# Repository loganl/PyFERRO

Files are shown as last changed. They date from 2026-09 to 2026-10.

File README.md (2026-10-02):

# PyFERRO — PHY445 phase-transition lab

Instrument control and data acquisition for a physics teaching lab: a lock-in amplifier
measures a sample's dielectric response while a PID controller ramps its temperature
through a phase transition. PyFERRO reads both instruments, plots live, and writes
self-describing data files. It replaces `FERRO v.2.vi`, a LabVIEW 2009 routine.

This repository holds the program and the lab manual for the experiment it serves.

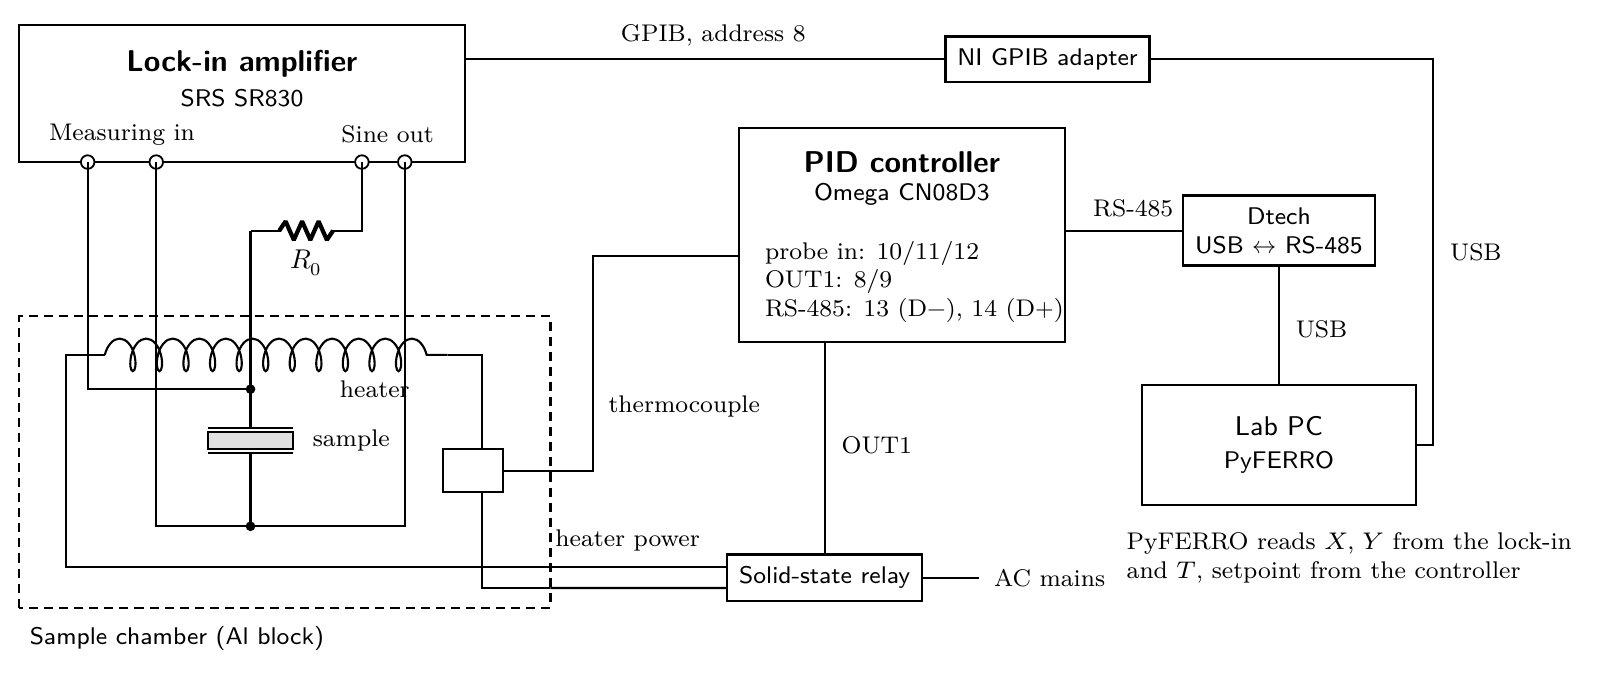
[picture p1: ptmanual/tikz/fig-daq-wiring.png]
Instrument wiring


## Try it without hardware

Needs [pixi](https://pixi.sh) only — it fetches Python and every dependency itself.

```bash
git clone https://github.com/loganl/PyFERRO.git
cd PyFERRO/pyferro
pixi run simulate          # the full GUI, driven by simulated instruments
pixi run -e test test      # the test suite: no hardware needed, GUI tests run offscreen
```

Simulation sits *below* the drivers, so the same parsing, scaling and file-writing code
runs as in the lab. Against real instruments it is `pixi run start`.

## Layout

| Path | What it is |
|---|---|
| `pyferro/ferro/` | the program: `gui/`, `acquisition.py` (the measurement loop), `instruments/` (drivers), `transports.py` (GPIB/serial), `config.py`, `datafile.py`, `analysis.py`, `sessionlog.py` |
| `pyferro/tools/` | `update.py` (the `git pull` before `pixi run start`) and `gpib_check.py` (`pixi run gpib`, a GPIB link diagnostic) |
| `pyferro/tests/` | drivers, wire-level protocol tests over a pty, GUI tests, version consistency |
| `pyferro/docs/` | `drivers-and-daq.md` and the instrument manuals |
| `ptmanual/` | LaTeX source of the lab manual, its figures and standalone TikZ sources |

**[`pyferro/README.md`](pyferro/README.md) is the complete documentation** — install,
wiring, taking data, file format, instrument protocols, code layout, tests and
releases. [`pyferro/docs/drivers-and-daq.md`](pyferro/docs/drivers-and-daq.md)
walks through the transports, drivers and measurement loop, and
[`pyferro/CHANGELOG.md`](pyferro/CHANGELOG.md) records each version.

## The hardware it talks to

| Instrument | Link | Protocol |
|---|---|---|
| SRS SR830 lock-in | GPIB (NI adapter), address 8 | IEEE 488.2 text commands, X/Y/R/θ in volts; its settings can also be set from the program |
| Omega CND3 PID controller | RS-485 via an FTDI USB adapter | Modbus ASCII/RTU, read-only |
| HP 34401A multimeter (optional) | GPIB, address 24 | `READ?`, Pt100 → °C (IEC 60751) |

The Instruments tab can also select the lab's previous lock-in, an **EG&G/PAR 5302**
(GPIB 12 on this rig), and a **Keithley 199** multimeter (GPIB 6).

The controller owns the heater; PyFERRO never writes to it. Instrument failures are
recorded as `nan` with a flag bit and the connection is reopened automatically, so a
dropped cable does not end a measurement.

The manuals for all five instruments are in `pyferro/docs/manuals/`, and the protocol
tests check the drivers against the example frames printed in them.

## How it ships

The lab PC runs a git clone of this repository (`C:\PyFERRO`) with pixi.
`pixi run start` does a `git pull --ff-only` first, so the lab always runs the latest
code on `main`; being offline just starts the copy already there. There is no
installer or bundle to build.

## Versioning

`MAJOR.MINOR.PATCH`, tagged `v<version>`. The number is written in exactly one place,
`__version__` in `pyferro/ferro/__init__.py`; the package metadata, the window title and
every data-file header derive from it, and a test fails if a second copy
appears or a tag disagrees. A file recorded in the lab names the version that produced
it, so it can always be traced back to the code.

## The lab manual

```bash
cd ptmanual && make        # builds the TikZ figures, then main.pdf
cd ptmanual && latexmk     # the same without make, for machines that lack it
cd ptmanual && make tagged # main-tagged.pdf, the tagged PDF/UA-2 edition for screen readers
```

It is built with **LuaLaTeX** from **TeX Live 2024 or newer** — the tagged-PDF
metadata and `luamml` are too new for older releases, and Debian's and Ubuntu's
packages lag behind. `ptmanual/.latexmkrc` and a `% !TEX program = lualatex` line in
every source file select the engine, so no flag is needed. The PDFs are committed,
so reading the manual needs no TeX at all. What to install, editor set-up and the
Overleaf route are in [`ptmanual/README.md`](ptmanual/README.md).

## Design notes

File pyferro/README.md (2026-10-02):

# PyFERRO — phase-transition data acquisition

Records **sample temperature** and the **lock-in X/Y signal** while an Omega CND3 PID
controller heats and cools the chamber. Replaces the LabVIEW routine `FERRO v.2.vi`.

| Instrument | Connection | Default |
|---|---|---|
| SRS SR830 lock-in | NI GPIB adapter | `GPIB0::8::INSTR` |
| Omega CND3 PID controller (holds the control thermocouple) | Dtech USB → RS-485 (FTDI) | Modbus ASCII, address 1, 9600 7E1 |
| HP 34401A multimeter (optional) | NI GPIB adapter | `GPIB0::24::INSTR`, Pt100 in 4-wire Ω |

Other models can be chosen on the Instruments tab: the lab's previous lock-in, an EG&G/PAR
5302 (GPIB 12 on this rig), and a Keithley 199 multimeter (GPIB 6). Choosing a lock-in
model moves the address to that model's, unless it was typed in by hand.

PyFERRO **reads** the controller and never changes its setpoints or heater power, so
the controller's *COMMUNICATION WRITE* setting stays **OFF**. The lock-in is the one
instrument it can set, from the Lock-in tab, and only when asked (§3).

This file is the complete documentation. [`CHANGELOG.md`](CHANGELOG.md) records what
changed per version; [`docs/drivers-and-daq.md`](docs/drivers-and-daq.md) explains the
code that talks to the instruments; `docs/` also holds the instrument manuals.

## 1. Install on the lab PC

Windows 10/11 64-bit. The lab PC runs a git clone at `C:\PyFERRO`.

1. Install [Git for Windows](https://git-scm.com/download/win) and
   [pixi](https://pixi.sh) (in PowerShell:
   `powershell -ExecutionPolicy ByPass -c "irm -useb https://pixi.sh/install.ps1 | iex"`).
   Neither needs admin rights.
2. Clone: `git clone https://github.com/loganl/PyFERRO.git C:\PyFERRO`.
3. Install the drivers once:
   * **NI-VISA** + **NI-488.2** for the GPIB adapter. A 64-bit VISA is required
     (`C:\Windows\System32\visa64.dll`); 32-bit-only installs from the LabVIEW 2009 era
     cannot be used from 64-bit Python.
   * **FTDI VCP driver** for the Dtech adapter, only if it does not appear as a `COM`
     port in Device Manager.
4. Start it from a terminal in `C:\PyFERRO\pyferro`:
   * `pixi run start` pulls the latest code (§8), then runs against the instruments;
   * `pixi run simulate` runs without hardware;
   * `pixi run gpib` diagnoses the lock-in's GPIB link (§5).

   The first start downloads Python and every dependency into `.pixi\` (allow
   ~1.5 GB of disk); later starts reuse it. After that, a start needs no internet:
   offline, the update step says so and the program starts as it is.

## 2. Hardware and wiring

wiring diagram

This is the lab manual's own figure: full size in
`../ptmanual/tikz/fig-daq-wiring.pdf`, source in `fig-daq-wiring.tex` beside it.

**RS-485** (two-wire half-duplex; the adapter's `RXD+`, `RXD-`, `GND` stay empty):

| Dtech terminal | CND3 terminal |
|---|---|
| `T/R+` | **14** (`D+`) |
| `T/R-` | **13** (`D−`) |

If the controller does not answer, swap the two wires first. Terminal numbers are those
of the 1/8 DIN size (CN08D3 = Delta DT340); other sizes number them differently.

**Controller settings** (Initial Setting mode): communication enabled, protocol ASCII,
address 1, 9600 baud, 7 data bits, even parity, 1 stop bit, communication write OFF.
Other settings work — use *Auto-detect settings*. The CND3 cannot use 7N1, 8O2 or 8E2.

**Identifying the controller:** during the first 3 s after power-on the top display's
4th character is `C` when RS-485 is fitted, and the bottom display's first two letters
are the OUT1/OUT2 types (`R` relay, `V` voltage pulse, `C` current, `L` linear voltage,
`S` SSR, `N` none). The lab unit is 43.8 × 90.9 mm behind the bezel (1/8 DIN, cutout
44.5 × 91.5 mm), 100–240 V AC.

**Lock-in:** the SR830, GPIB address 8. The sensitivity and expand settings are read
from the instrument with every reading, so X and Y are always scaled correctly. The rest
of the set-up follows the lab manual's SR830 table (for the 5302, the set-up from the
manual's former 5302 table):
*Test lock-in* compares the instrument with it, and the Lock-in tab can set it (§3).

**Multimeter (optional):** the HP 34401A must be switched to **4-wire Ω** on its front
panel — PyFERRO does not change its function, and on 2026-09-29 it was found set to DC
volts. The Keithley 199 is set to ohms by PyFERRO on every connection and picks 2- or
4-wire by whether the SENSE leads are connected, but its **FRONT/REAR** input switch is
mechanical: it must select the terminals the Pt100 is wired to.

**Safety:** the chamber is hot above 100 °C and the lab manual forbids exceeding 160 °C.
PyFERRO warns above that but is not a safety device; the controller and relay are.

## 3. Taking data

1. **Instruments tab:** check the lock-in **Model** (SRS SR830 on this rig), pick the
   Dtech COM port (FTDI ports listed first), press **Test lock-in** and
   **Test controller**. A green ✔ shows the sensitivity, time constant and reference
   frequency, and PV/SV, output level, control mode and firmware. A table underneath
   compares every lock-in setting with the lab manual's table for that model and says
   which key changes any that differ; starting a recording repeats the check and logs
   any difference as a warning.
2. **Lock-in tab:** shows the chosen model's settings. *Read from lock-in* fills them in;
   change them there and press *Apply to lock-in* (it lists the commands and asks
   first), or press *Lab-manual values* to fill in the lab manual's table, then Apply.
   Only what differs is sent, and the settings are read back afterwards. This works
   during a run too: the change is sent between samples and written into the data file.
   The phase tuning stays on the front panel, as does turning an SR830 offset or expand
   on (the tab can turn them off), and on the 5302 its AC/DC and FLOAT/GND keys.
3. **Run tab:** enter a sample/run name (becomes the file name), operator, drive details,
   notes, and the save folder.
4. **▶ Start monitoring** (F5) shows live data without saving. **● Record** (Ctrl+R)
   opens a file, starting monitoring if needed; pressing it again closes that file, and
   the next recording opens a new one. **■ Stop** disconnects.
5. Set the **reading interval** to at least ~5× the lock-in time constant.
   *Save only if ΔT ≥* reproduces the old LabVIEW behaviour; leave it off to record
   every reading.
6. **Temperature from** (Run tab) selects what goes in column 1 of the file: the
   *CND3 controller* probe (normal) or the *Multimeter Pt100*. Both are recorded
   whenever available — `PV_C` from the controller, `T_dmm_C` from the multimeter.
   To use the multimeter, tick **Also read the multimeter** on the Instruments tab and
   check its model, its GPIB address (`GPIB0::24::INSTR` for the 34401A,
   `GPIB0::6::INSTR` for the Keithley 199 on this rig) and whether the reading is ohms
   (a Pt100, converted here) or already °C (34401A only).

The tiles above the plots show the sample temperature, setpoint, ramp direction and
rate, X, Y and R/θ; the plots show temperature against time and X and Y against
temperature, heating and cooling in different colours.

Status lights: green OK, red not answering (hover for the reason), grey unused. A failed
reading never stops a run — the value becomes `nan`, a flag is set, and the instrument is
reopened after three consecutive failures. The first three temperatures after the
controller or multimeter connects are discarded (`nan`, flag 16) so a start-up glitch
cannot squash the plot. The temperature tile turns red above the
chamber limit (default 160 °C).

Settings persist in `%USERPROFILE%\.ferro\settings.json`; delete it to reset, or set
`FERRO_CONFIG_DIR` for a per-group file.

## 4. Data files

`<name>_YYYYMMDD_HHMMSS.txt`, never overwritten, flushed after every row.

```
# created: 2026-09-29T15:02:11
# software: pyferro 1.1.0
# sample: BTO_1V_37kHz
# temperature_source: CND3 controller PV
# lockin_model: SR830
# lockin_sensitivity: 1 V
# lockin_time_constant: 300 ms
# lockin_setup_check: matches the lab manual's SR830 table
# controller_sv_c: 150.0
# column 1: T_C - sample temperature used for plots (degC)
# T_C	X_V	Y_V	time_s	R_V	theta_deg	SV_C	PV_C	T_dmm_C	sens_V	direction	segment	flags
2.71944e+01	1.00420e-04	-2.32000e-03	0.00000e+00	...
```

| # | Column | Meaning |
|---|---|---|
| 1–3 | `T_C`, `X_V`, `Y_V` | as in the LabVIEW files: temperature (°C), lock-in X and Y (V rms) |
| 4 | `time_s` | seconds since the run started |
| 5–6 | `R_V`, `theta_deg` | √(X²+Y²) and atan2(Y, X) |
| 7–8 | `SV_C`, `PV_C` | controller setpoint and temperature |
| 9 | `T_dmm_C` | multimeter Pt100 temperature (`nan` when unused) |
| 10 | `sens_V` | lock-in full-scale sensitivity at that moment |
| 11–12 | `direction`, `segment` | +1 heating, −1 cooling, 0 not yet known; segment increments at each turn-around. The column switches 1–2 min after a turn; the `# Ramp turned … at T °C, t = … s` line in the file gives where it really was |
| 13 | `flags` | 1 lock-in overload, 2 lock-in error, 4 controller error, 8 multimeter error, 16 temperature discarded just after connecting (added together) |

Missing values are `nan`. Load with `numpy.loadtxt(path)`, or:

```python
names = "T_C X_V Y_V time_s R_V theta_deg SV_C PV_C T_dmm_C sens_V direction segment flags".split()
df = pd.read_csv(path, sep=r"\s+", comment="#", names=names)
heating = df[df.direction == 1]
```

*Old LabVIEW file format* writes only T, X, Y with no header (readable by `plot.vi`);
the metadata then goes to a `.json` file of the same name.

**Events inside the file.** Anything that changes what the numbers mean is written into
the data file as a `#` comment line at the moment it happens — a sensitivity or time
constant change, and any change of reference, oscillator level or frequency, filters,
reserve, input, coupling, grounding, displays or phase (checked every minute, and at once after a
change from the Lock-in tab, which is itself recorded), an overload starting or clearing, the controller switching to STOP, a
changed reading interval or temperature source, edited notes. `numpy.loadtxt` and pandas
skip these lines, so nothing breaks; the header also names the port each instrument used
(`# connection_lockin:`, `# connection_pid:`).

**Session log.** Everything the log panel shows is also written to
`~/.ferro/logs/pyferro_<start>.log`, from the moment the program starts — so the
messages that explain a run (an instrument that never answered, an auto-detect that
found nothing) survive even though they happened before recording began. Each data file
names it in its header (`# session_log:`) and gets a copy beside it as `<name>.log` when
the recording closes, so the data and its explanation travel together. The twenty newest
logs are kept; a log that cannot be written is skipped silently and never interrupts a
measurement.

## 5. Troubleshooting

| Symptom | Cause and fix |
|---|---|
| `update: …` line at start | `pixi run start` says what its `git pull` did. Offline, a local edit in the way, or a folder that is not a clone never stops the start; if it says the dependencies changed, close and start again. |
| `pixi` or `git` is not recognised | Not installed, or the terminal was opened before installing; install it (§1) and open a new terminal. |
| Qt/DLL errors at start-up | The clone is on a network drive; clone to a local disk. |
| `Could not open GPIB0::12::INSTR` | NI-VISA/NI-488.2 missing, adapter unplugged, or wrong address — check NI MAX. |
| Lock-in connects only sometimes | Run `pixi run gpib`: it opens a fresh connection twenty times, as a program start does, and reports the success rate. Use it before and after reseating a connector or swapping a cable, rather than trusting a single Test. |
| NI MAX says the 5302 "did not respond to a \*IDN? query" | Normal: the 5302 predates `*IDN?` (it answers `ID`). The scan did find it. |
| *Find* lists no VISA instruments | 32-bit-only NI-VISA; install a current one with `visa64.dll`. |
| GPIB reads all time out, but the bus enumerates | **Another instrument on the chain is powered off.** GPIB's handshake needs every connected device powered; an unpowered one holds NRFD/NDAC low, which also makes a scan "find" a device that never answers. Switch the multimeter on — even when PyFERRO is not using it — or take it out of the cable chain. |
| Readings arrive far slower than the interval | An instrument that is not answering costs its whole timeout every sample. The log says which one, every 30 s. |
| `expected ID 5302, instrument answered …` | Another instrument at that GPIB address. |
| X values ×10 off | Check the EXPAND (`EX`) indicator; it multiplies X only. PyFERRO accounts for it, the LabVIEW VI did not. |
| X/Y tile red "OVERLOAD" | Signal beyond 120 % of full scale — use a less sensitive range. |
| "Lock-in settings differ from the lab manual" | A setting is not the lab manual's value; the Instruments tab's table says which key changes it, or use the Lock-in tab. A warning only — recording goes ahead. |
| Readings jump between rows | Interval shorter than ~5× the time constant. |
| `No valid reply from CND3` | Wrong COM port, wires swapped (14 = D+, 13 = D−), communication disabled, or different settings — run *Auto-detect settings*. |
| `temperature sensor not connected` | The controller reports a probe fault (`8003H`); check terminals 10/11/12. |
| `controller initialising` | Normal for a few seconds after power-on (`8002H`). |
| `controller sent …H, a status code, not a temperature` | A value below −999.9 °C, which no input can read. The first readings after connecting are discarded for this reason (flag 16); if it recurs mid-run, check the probe wiring. |
| `multimeter reads … expected ~100-200 ohm` | The 34401A is not in 4-wire Ω (set it on the front panel), or the Pt100 is not connected. |
| Keithley 199 reads `OOHM+9.999999E+9` / "overflow" | Open circuit: nothing across the inputs in use. Check the Pt100 leads and that the FRONT/REAR switch selects the terminals they are on. |
| Temperature in °F | The controller is set to Fahrenheit; PyFERRO records what it reports. |
| COM port disappears | FTDI/driver issue or unplugged adapter; press *Refresh* — the loop reconnects by itself. |
| Nothing is saved | The Record button must be red; check the log panel. |
| "Cannot save here" / write error mid-run | Folder read-only or the USB drive vanished; rows already written are intact. |
| Fewer rows than expected | *Save only if ΔT ≥* is set. |
| Plots slow after hours | Press **Clear plots**; the file is unaffected. |

## 6. Instrument protocols

Manuals in `docs/manuals/`. `tests/test_protocols.py` checks
the code against the example frames printed there.

**EG&G 5302** (manual chapters 8–9): `ID` → `5302`; `XY` → X and Y with **±10000 = full
scale** (±12000 max); `SEN`/`SEN n` sensitivity index 0–21 (100 nV … 1 V, 1-2-5);
`XTC`/`XTC n` time-constant index 0–18; `EX` → 1 when Expand X is on (x channel ×10, y unaffected);
`FRQ` → reference frequency in mHz. The front-panel set-up is read with `IE` (reference
INT/TTL/EXT), `OA` and `OF` (oscillator level and frequency, each as a count and a
range), `DR` (dynamic reserve), `FLT` (filter), `PREAMP` (signal input) and `P`
(reference phase), and each command with a number sets that value — how the Lock-in tab
applies the lab manual's table. AC/DC coupling and FLOAT/GND have no command.

`V = counts / 10000 × full_scale`, with X (only) divided by 10 when expand is on. `SEN` and `EX` are
read before every `XY`. `XY` is the compound command `X;Y`, so the two numbers arrive
either on one line (separated by the `DD` delimiter) or as two terminated lines — the
driver reads a second line when only one number arrives. GPIB (address 12) or RS-232;
over RS-232 the instrument echoes characters and ends each exchange with `*` (OK) or
`?` (error/overload/unlock), at 9600 7E1.

**Omega CND3 / Delta DT340:** Modbus ASCII (default) or RTU, function 03H reads up to
8 words, 06H writes one. PV and SV are read in one request.

| Register | Content |
|---|---|
| `1000H` | present value (PV), signed, 0.1° units |
| `1001H` | set value (SV), signed, 0.1° units |
| `1005H` | control method: 0 PID, 1 ON/OFF, 2 manual, 3 fuzzy |
| `1012H`, `1013H` | output 1 and output 2 levels, 0.1 % units |
| `102AH` | LED status: bit 2 = °C, bit 3 = °F |
| `102FH` | firmware version (`0x0100` = V1.00) |
| `103CH` | run/stop: 0 STOP, 1 RUN, 2 END, 3 HOLD |
| `1104H`, `1124H` | setpoint ramp rate (0.1°) and its unit (0 per minute, 1 per second) |
| `110EH` | output 1 upper limit, 0.1 % units |
| `1120H` | setpoint mode: 0 constant, 1 slope, 2 program, 3 remote |

PV and SV are read every sample; the control method and run state every minute; the
rest by *Test controller* and for the data-file header.

PV values `8002H` initialising, `8003H` sensor not connected, `8004H` sensor input error,
`8006H` ADC error, `8007H` memory error are faults, not temperatures. *Auto-detect* tries
ASCII then RTU across the documented baud rates and framings, reading `102FH`.
Limitation: during a ramp `1001H` holds the programmed setpoint; the moving setpoint
(`1036H`, program mode) is not read.

**HP 34401A:** `*IDN?` to identify; `READ?` returns the displayed value. PyFERRO does
not set the function: in 4-wire ohms (set on the front panel) that is the Pt100
resistance, converted with IEC 60751 (`R = R₀(1 + AT + BT²)`, A = 3.9083×10⁻³,
B = −5.775×10⁻⁷). A reading outside 0.5–3 × R₀ (50–300 Ω for a Pt100) raises an error
naming the likely cause. With *Reading* set to °C the value is recorded as it comes.

**SRS SR830** (manual chapter 5), GPIB only, LF terminators both ways, address 8:
`OUTX 1` at connection so answers go to GPIB, `*IDN?` to identify. Each sample reads
`SENS?` (index 0–26, 2 nV … 1 V), `OEXP? 1/2/3` (offset and expand of X, Y and R),
`SNAP? 1,2,3,4` (X, Y, R, θ in volts and degrees, X and Y from one instant), then
`LIAS?`. That status byte latches and is cleared by reading it, so an overload at any
time since the previous sample sets the overload flag. Reading the byte clears it, so
if the read needs a retry the sample is flagged as overloaded too. The manual does not say whether
`SNAP?` includes the output offset and expand; when either is set, at the start or
later, the log says so and the header records them, so check the recorded X/Y against the display.
The set-up is read with `FMOD?` (reference), `FREQ?`, `SLVL?` (sine output level),
`ISRC?`, `ICPL?`, `IGND?` (input, coupling, grounding), `ILIN?` (line notches), `RMOD?`
(reserve), `OFSL?` (filter slope), `DDEF? 1/2` (displays) and `PHAS?`, and each command
with a value sets it — how the Lock-in tab applies the lab manual's table. Several go on
one line separated by `;` (5-1), which is how `OEXP 1,0,0;OEXP 2,0,0;OEXP 3,0,0` turns
every offset and expand off. The sine output's resistance is 50 Ω: the lab manual's R₀.

**Keithley 199** (manual section 3.9): no `*IDN?`; `U0X` returns a status word starting
`199`. Connecting sends a device clear, which resets the meter, so the program sets
ohms, autorange, zero off and prefixed readings itself (`F2R0T0B0Z0G0X`). Readings look like
`NOHM+1.100000E+2`: a leading `O` means overload and is reported as an error rather
than as its all-9s value, and anything other than `OHM` means someone changed the
function. The 199 picks 2- or 4-terminal ohms by whether the SENSE leads are
connected. It has no °C function, so only the Pt100 reading is offered.

## 7. Code layout

```
ferro/gui/          main_window.py  window, plots, readouts, log
                    setup_panel.py  instrument settings, Test / Auto-detect
                    lockin_panel.py the Lock-in tab: read and set the lock-in
                    widgets.py      status lights, readouts, background tasks
ferro/acquisition.py   the measurement loop: open, read, log, retry
ferro/instruments/  lockin5302.py, sr830.py, cnd3.py,
                    hp34401a.py, keithley199.py, simulated.py
ferro/transports.py VisaTransport (GPIB), SerialTransport (RS-232 echo + prompt)
ferro/config.py     settings dataclasses, saved as JSON
ferro/datafile.py   the writer
ferro/analysis.py   ramp-direction tracking
ferro/sessionlog.py the session log
tools/update.py     the git pull before pixi run start
tools/gpib_check.py pixi run gpib: step-by-step GPIB diagnosis with a verdict
```

[`docs/drivers-and-daq.md`](docs/drivers-and-daq.md) walks through the transports, the
instrument drivers and the acquisition loop in depth, with the real bytes from this rig.

Each loop pass first handles a Record or Lock-in-tab request; then reads the
controller, the multimeter if enabled, then the lock-in; picks the temperature source;
updates direction and segment; emits the row to the GUI; writes it when recording;
re-reads the slower settings once a minute; and sleeps to the next tick without
catching up. Instrument I/O
happens only on the acquisition thread and reaches the GUI through Qt signals; *Test*
buttons and the stop sequence run as short-lived worker tasks; each transport serialises
its own calls with a lock.

## 8. Tests and simulation

```bash
pixi run start                     # git pull, then run against the real instruments
pixi run start --skip-deps         # the same without updating first
pixi run simulate                  # the GUI with simulated instruments
pixi run gpib [GPIB0::12::INSTR]   # diagnose the 5302's GPIB link (it asks ID, so 5302 only)
pixi run -e test test              # everything (GUI tests run offscreen)
pixi run -e test test -k protocol  # one group
```

`pixi` installs the environment on first use; no other setup is needed on a development
machine (macOS, Linux or Windows).

`pixi run start` first runs `tools/update.py`, which does `git pull --ff-only` so a
git clone (such as the lab PC's `C:\PyFERRO`) always starts on the latest code. It never
stops the program starting: offline ("update: offline", after at most 10 s), a local
edit in the way, or a folder that is not a clone each print one line and start the code
as it is. If the pull changed the
dependencies, it says to close and start again so pixi can install them.

| File | Covers |
|---|---|
| `tests/test_core.py` | scaling, parsing, register decoding, Pt100, every driver against a fake of its manual's protocol, setting both lock-ins and checking them against the lab manual, data files, direction tracking, settings, a simulated run |
| `tests/test_protocols.py` | real serial/Modbus code over a pty against manual-accurate emulators (skipped on Windows) |
| `tests/test_gui.py` | record/stop cycles, run-name guard, one file per recording, plots after Clear, window width, the Test button for every model, other models recorded and kept in the settings, the Lock-in tab for each model, idle and during a run, the address following the model |
| `tests/test_version.py` | one version everywhere, matching the git tag |

`tools/` has no tests: `update.py` and `gpib_check.py` are checked by running them.

Simulated instruments sit **below** the drivers, so the same parsing and scaling code
runs: a shared fake sample ramps 25 → 150 → 25 °C at 30 °C/min with a peak at 122 °C,
and the controller exposes the CND3 registers. Whichever lock-in is chosen on the
Instruments tab starts in the lab manual's set-up for it, apart from a 50 mV
sensitivity, and accepts the Lock-in tab's commands: the SR830 answers its own commands
in volts, the 5302 `ID`/`SEN`/`XTC`/`EX`/`FRQ`/`XY` with counts scaled to the current
range. The Keithley 199 gives prefixed ohms readings. Simulated runs show an orange
banner and `simulation: True` in the file header. Simulation cannot reproduce timing,
bus noise, wiring faults or GPIB itself — check those with the *Test* buttons and
`pixi run gpib`.

## 9. Versioning and releases

One number, in one place:

```python
# ferro/__init__.py
__version__ = "1.1.0"
```

`pyproject.toml` takes it dynamically, the window title and every data-file header show
it, `pixi.toml` has no version field, and the release is tagged `v<version>`.
`tests/test_version.py` fails if a second copy appears or the tag disagrees.

The lab PC runs whatever is on `main`, so a release is a tag marking a tested state,
not something to install. To release, on an up-to-date, clean `main`:

```bash
# 1. edit __version__ in ferro/__init__.py, and add "## 1.1.0 — <date>" to CHANGELOG.md
pixi run -e test test
git commit -am "PyFERRO 1.1.0"
git tag -a v1.1.0 -m "PyFERRO 1.1.0"
git push origin main v1.1.0
```

Patch: fixes and docs. Minor: features, new options, a column added on the right.
Major: data-layout or workflow changes that break existing analysis scripts.

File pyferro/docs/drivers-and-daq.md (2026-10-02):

# Drivers and DAQ

How PyFERRO turns bytes on a GPIB cable and an RS-485 pair into a row in a data file —
from the wires up to the measurement loop, with every example taken from this rig.

1. [The layers](#1-the-layers)
2. [The wires](#2-the-wires-just-enough-to-read-the-code)
3. [Transports](#3-transports)
4. [Drivers](#4-drivers)
5. [DAQ](#5-daq)
6. [One sample, traced](#6-one-sample-traced)
7. [Check yourself](#7-check-yourself)

## 1. The layers

| Layer | Files | Job |
|---|---|---|
| GUI | `gui/main_window.py`, `setup_panel.py`, `lockin_panel.py` | Draws plots and readouts. Never talks to an instrument the loop has open. |
| **DAQ** | `acquisition.py` | When to read, what to do when a read fails, what to save. |
| **Drivers** | `instruments/sr830.py`, `lockin5302.py`, `cnd3.py`, `hp34401a.py` (+ other models, §4) | What the instrument's answers mean. |
| **Transports** | `transports.py`, minimalmodbus | How bytes get there and back. |
| OS / vendor | NI-VISA → NI-488.2; pyserial → FTDI | Hardware access, from outside this repo. |
| Wires | GPIB → SR830 (or 5302); RS-485 → CND3 terminals 13/14 | Electrical signals. |

Each layer talks only to the one directly below it. `Lockin5302` never mentions GPIB;
`Acquisition` never mentions `SEN`. That separation is why simulation works: replace the
bottom of the stack and everything above runs unchanged. This document covers the three
layers in bold.

## 2. The wires, just enough to read the code

### GPIB (IEEE-488)

A parallel bus: eight data lines plus control lines. One **controller** — the NI
GPIB-USB-HS, at address 0 — shares it with up to 30 devices, each with a **primary
address**. The 5302 is PAD 12. Before data moves, the controller *addresses* the bus:
"12, listen" or "12, talk".

Every byte crosses with a three-wire handshake:

- **NRFD**, not ready for data — a listener holds it until it can take a byte
- **DAV**, data valid — the talker asserts it once the byte is on the lines
- **NDAC**, not data accepted — a listener holds it until it has the byte

So the bus runs at the speed of its slowest listener. Two failures seen on this rig
follow directly: an **unpowered instrument** holds these lines down and nothing moves;
and **"no listeners" (ENOL)** means NRFD and NDAC were both released when the controller
started — nobody was there to hold them.

A message ends with the **EOI** line on its last byte, and/or a **terminator byte**: CR
(`0x0D`) or LF (`0x0A`). Two more bus operations appear in the code. A **serial poll**
reads one status byte from a device, answered by its interface chip rather than its
command processor. **Device Clear** resets a device's interface and buffers.

### RS-485

The signal is the voltage *difference* between two wires, D+ and D−, which makes it
resistant to noise. It is half-duplex — one side talks at a time — and multi-drop, so
the protocol carries a device address; the CND3 is Modbus address 1. The Dtech adapter
appears to Windows as an ordinary COM port.

Characters travel as asynchronous serial. At **9600 7E1** each is 1 start + 7 data + 1
parity + 1 stop bit = 10 bits, about **1.04 ms per character**.

### VISA

A vendor-neutral API: open a *resource* by name (`GPIB0::12::INSTR`), then write, read,
set a timeout, set terminators, read the status byte, clear. NI-VISA implements it on
NI-488.2; **pyvisa** wraps it for Python. The `@py` backend, pyvisa-py, is pure Python
and **cannot** drive NI GPIB hardware.

## 3. Transports

Source: [`ferro/transports.py`](../ferro/transports.py)

Every driver needs exactly three calls, and that is the whole contract:

```python
write(cmd)          # send; no reply expected
query(cmd) -> str   # send; return the reply text
close()
```

`VisaTransport` and `SerialTransport` implement it for real hardware, and the simulator
has one fake per instrument model (`SimLockinTransport` for the 5302, `SimSR830Transport`,
`SimDMMTransport`, `SimK199Transport`).

### Terminators, as actual bytes

This is what `ibic` showed on the rig:

| Direction | Bytes | Meaning |
|---|---|---|
| PC → 5302 | `49 44 0D` | "I" "D" CR — write termination CR |
| 5302 → PC | `35 33 30 32 0D` | "5" "3" "0" "2" CR — read termination CR |

pyvisa appends `write_termination` to everything it sends, and stops reading at
`read_termination`. If that byte never comes, the read runs to the timeout and fails
with `VI_ERROR_TMO` — indistinguishable from a dead instrument. `None` means stop only
on EOI.

`probe_terminations` tries each pair in `TERMINATIONS` in order. It is generic: the
caller passes in `open_one(write, read)` and `verify(transport)`, so it knows nothing
about the 5302. It keeps the first pair that verifies, closes every rejected transport,
and tags the winner with `.terminators` so the caller can try that pair first next time.

### `VisaTransport`, method by method

- **`__init__`** tries NI-VISA, then `@py`; opens the resource; sets the timeout (in ms)
  and both terminators; sends **Device Clear**, which also empties replies a previous
  program never collected.
- **`_lock`** exists because two threads can reach one instrument: the acquisition loop
  and a **Test** button's worker. Without it their bytes interleave on the bus and each
  reads the other's reply.
- **`query`** loops `retries + 1` times. After a failure it serial-polls and decodes the
  status byte, drains stale replies, then tries again. When the retries run out it
  raises `TransportError` with the decoded reason attached, and `retries_used` counts
  how often it had to.
- **`_pause`** is the 50 ms gap: the 5302 loses a command that arrives while it is still
  busy with the last one.
- **`reply_delay_s`** is a second 50 ms wait, between sending a query and reading its
  reply (`pyvisa`'s `query(delay=...)`). The instrument must parse the command before it
  can talk; addressed too soon, its reply is late and the *next* query reads it. On the
  rig this was the difference between the Test button failing 10 times in 10 and
  succeeding 15 in 15. The multimeter leaves it at 0.
- **`_recover` / `drain_replies`** handle a subtle trap. A query that *times out* can
  still have its reply arrive afterwards, and then the *next* query reads that late
  reply instead of its own — which is how `5302` once turned up as a sensitivity index.
  Draining with a 200 ms timeout discards anything in flight.
- **`read`** fetches one more line, for when `XY`'s two values arrive separately.

### `SerialTransport` — the same contract over RS-232

Over RS-232 the 5302 echoes each character, sends its reply ending in CR LF, and then
sends a **prompt**: `*` if all is well, `?` on an error. `_exchange` clears the input
buffer, writes, reads 64-byte chunks until the tail ends in a prompt, and strips the
echo. It accepts a prompt in only three positions: as the whole message, after a CR/LF,
or right after the echoed command (a command with no reply).

> The prompt marks the end of every exchange, so serial replies **cannot** get out of
> step. GPIB has no such marker — which is why the VISA side needs draining and range
> checks and the serial side does not.

## 4. Drivers

### Lock-in: `Lockin5302`

Source: [`ferro/instruments/lockin5302.py`](../ferro/instruments/lockin5302.py)

| Command | Returns |
|---|---|
| `ID` | `5302` |
| `SEN` | sensitivity index 0–21: 100 nV to 1 V in a 1-2-5 sequence |
| `EX` | 1 when Expand X is on |
| `XTC` | time-constant index 0–18 |
| `FRQ` | reference frequency in **mHz** |
| `XY` | X and Y as integer **counts** |
| `IE`, `DR`, `FLT`, `PREAMP` | codes for reference mode, dynamic reserve, filter, signal input |
| `OA`, `OF` | oscillator level and frequency as `n1 n2`: a count and its range |
| `P` | reference phase as `quadrant millidegrees` |

The last three rows are read by `setup()`, for the **Test** button, the data-file header,
the Lock-in tab and the once-a-minute poll during a run (§5) — a record of how the front
panel was set, following the 5302 capacitance set-up. Each is read on its own and becomes
`not read` if it fails, so a dropped exchange there cannot fail a Test or a recording.
AC/DC coupling and FLOAT/GND are latching keys with no GPIB command and cannot be read
at all.

**Setting the 5302.** Every command above that reads a value also sets it when given a
number: `SEN 21`, `XTC 8`, `EX 0`, `IE 0`, `OF 2500 7`, `OA 5000 1`, `DR 1`, `FLT 0`,
`PREAMP 1`. `SETTABLE` lists what the driver can set, in the order `apply()` sends it
— the time constant before the reserve, because a FAST time constant forces MIN reserve
(manual §4.3). `commands_for` builds every command, checking each value, before
`apply()` sends the first, so a bad value sends nothing. `oscillator_frequency_command`
and `oscillator_level_command` do the count-and-range encoding: 25 kHz is `OF 2500 7`
(2500 in the 10–100 kHz decade), 0.5 V is `OA 5000 1` (5000 steps of 0.1 mV).

**Checking the set-up.** `CAPACITANCE_SETUP` is the 5302's capacitance set-up as data
— setting, wanted value, and which front-panel key changes it — and
`check_setup(settings)` compares a `settings()` dict with it row by row: ✔, ✘, or "not
read". The Test button shows the result as a table, a recording writes it into the
header (`# lockin_setup_check:`), and the Lock-in tab's *Lab-manual values* fills its
form from the same table. It was the lab manual's 5302 table until the manual moved to
the SR830 and dropped the 5302; the SR830 driver's `CAPACITANCE_SETUP` is the one to keep
in step with `ptmanual/main.tex` now.

The instrument speaks **counts, not volts**. ±10000 counts is full scale; readings run to
±12000 before clipping.

```
V = counts / 10000 × full_scale[SEN]
X only: ÷ 10 again when EX = 1
```

**Expand multiplies the gain of the x channel only** — manual §4, "causes the x channel
output to be multiplied by 10". Y keeps its full scale.

Worked example: `SEN` answers 17 (50 mV full scale) and `XY` answers `5000,-2500`. Then
X = 5000/10000 × 50 mV = **25 mV** and Y = **−12.5 mV**. With Expand on, X becomes
**2.5 mV** and Y stays **−12.5 mV**.

**Why `read()` asks for `SEN` and `EX` every sample:** if a student presses SEN↑
mid-run, the same counts now mean different volts. The LabVIEW routine scaled with a
value stored once at the start, which is how the 2025 data came out pinned at
1.00×10⁻⁷ V. Two short exchanges per sample buy scaling that cannot go stale. If either
fails, the sample is lost rather than guessed.

- **`XY`** may arrive on one line or two. The regex collects every integer; if it found
  only one, the driver reads another line.
- **`parse_ints`** matches `[-+]?\d+`, so it ignores whatever delimiter separates the
  values — the `DD` command can set any character.
- **`checked_index`** treats an index outside 0–21 or 0–18 as "replies out of step", not
  as a range we don't know about. The manual's tables 9-16 and 9-19 match ours.
- **`LockinReading`** carries the result, with derived `r_v` = √(X²+Y²), `theta_deg`,
  `overloaded` (≥ 12000 counts) and `percent_fs`.

### Controller: `CND3` and minimalmodbus

Source: [`ferro/instruments/cnd3.py`](../ferro/instruments/cnd3.py)

**Modbus in brief.** The device is a table of 16-bit **registers**. Function **03**
reads a run of them. A request names the device address, the function, a start register
and a count; the reply gives a byte count, then the values; a checksum closes every
frame. Here is the request PyFERRO sends every sample:

```
:  01  03  1000  0002  EA  CR LF
│  │   │   │     │     └─ LRC checksum
│  │   │   │     └─ read 2 registers: PV and SV
│  │   │   └─ starting at register 1000H (PV)
│  │   └─ function 03, read
│  └─ Modbus address 1
└─ start of frame
```

**LRC:** add the bytes, `01+03+10+00+00+02 = 0x16`, then take the two's complement,
`(−0x16) & 0xFF = 0xEA`.

The reply is `:01 03 04 05DC 0640 D1`: four data bytes, where `05DC` = 1500 →
**150.0 °C** process value and `0640` = 1600 → **160.0 °C** setpoint.

`decode_temperature` checks the fault codes 8002H–8007H first, then reads the word as
signed 16-bit and divides by ten: `FFF6` → 65526 − 65536 = −10 → **−1.0 °C**. Anything
below −999.9 °C is refused as a status code: no input goes that low, and an unlisted
code such as `8000` would otherwise become **−3276.8 °C** — the "−3000 °C" spikes once
seen on the first readings of a run.

**Who does what.** minimalmodbus builds the frame, computes the LRC (or CRC-16 for RTU,
the same content in raw binary), sends it through pyserial, and validates the reply's
checksum, address and function. `CND3` just asks for `read_registers(0x1000, 2)` and
interprets the answer. Its `_read` retries twice, sleeping 50 ms then 100 ms, and it
**never writes** — so it cannot touch the setpoint or the heater. `autodetect` works
through mode × baud × framing, asking for the firmware register until something answers.

Beyond PV and SV, `status()` gathers what **Test controller** shows and the data-file
header records: firmware, output 1 level, control method (1005H), run state (103CH) and
°C/°F, plus `setup()` — output 2, output 1's upper limit, the setpoint mode and its ramp
rate. Like the 5302's `setup()`, each of those is read on its own and becomes `None` if
it fails, because they explain a run rather than measure it.

On the wire, 17 characters out and 19 back is about **37 ms**, plus the controller's own
response time.

### Multimeter: `HP34401A`

Source: [`ferro/instruments/hp34401a.py`](../ferro/instruments/hp34401a.py)

`READ?` returns whatever the meter is measuring: the driver sends no function command,
so the meter must be put in 4-wire ohms on its front panel. The driver solves the
Callendar–Van Dusen quadratic R = R₀(1 + A·T + B·T²) for T: 109.73 Ω → 25.0 °C,
157.33 Ω → 150.0 °C. A sanity window of 0.5–3 × R₀ catches a meter left in the wrong
mode — on the rig it was once found on DC volts.

### Other models: one shape, several drivers

The lab's lock-in is now the SRS SR830, the default; the 5302 above, its predecessor, is
still supported, and the walkthrough uses it because its quirks are the instructive
ones. The multimeter can be a 34401A or a Keithley 199. `open_lockin` and `open_dmm`
look the driver up in `LOCKIN_MODELS` / `DMM_MODELS`, and nothing above them knows which
one they got, because every lock-in driver has the same methods (`check`, `read`,
`settings`, `apply`, `close`) and attributes (`MODEL`, `SENSITIVITY_LABELS`,
`TIME_CONSTANT_LABELS`, `EXPAND_NAME`), and every reading the same fields (`x_v`, `y_v`,
`r_v`, `theta_deg`, `sensitivity`, `full_scale_v`, `percent_fs`, `expand`,
`overloaded`). The multimeters share `check`, `read_raw`, `read_celsius`, `close` and
`MODEL`.

Each lock-in driver also describes its own settings, so the GUI and the loop need no
per-model code: `SETUP_TABLE` (its lab-manual table, checked by the shared
`check_setup`), `SETUP_NAME`, `SETUP_NOTE`, `PANEL` (the Lock-in tab's controls:
key, label, and a kind — a choice, a position in a list, kHz, volts or a check box),
`PANEL_NOTE` (what only the front panel can do), and `commands(changes)`, which builds
and checks every command before anything is sent. The Lock-in tab rebuilds itself from
`PANEL` when the model changes.

What differs is what the manuals say, and each difference shows up somewhere specific:

- **SR830** ([`sr830.py`](../ferro/instruments/sr830.py)) is IEEE 488.2 and does its own
  flow control, so it gets fixed LF terminators and none of the 5302's delays. It answers
  in volts, so there is no scaling. Its overload status byte **latches and clears on
  read**. The driver reads it exactly once per sample, after the data. Two reads (say one
  for overload, one for unlock) would each clear what the other was looking for. For the
  same reason a retried read may have lost the bits, so a sample whose status read
  needed a retry is flagged as overloaded. Every front-panel setting has a command, so
  unlike the 5302 nothing is unreadable: `setup()` reads `FMOD?`, `SLVL?`, `ISRC?`,
  `ICPL?`, `IGND?`, `ILIN?`, `RMOD?`, `OFSL?`, `DDEF?` and `PHAS?`. `SETTABLE` sends the
  reference first (`FREQ` is refused unless it is internal) and the reserve and slope
  before the time constant, which the instrument raises to the shortest they allow.
  Several commands can share a line, separated by `;`: that is how one entry turns
  every offset and expand off.
- **Keithley 199** ([`keithley199.py`](../ferro/instruments/keithley199.py)) has no
  `*IDN?`, like the 5302. The device clear that `VisaTransport` sends on opening resets
  it, so the driver sets its own function, and turns Zero off, every time. Its readings carry a prefix, and
  that prefix is the only place an overload shows: without it, overflow is a
  plausible-looking 9.999999E+9 Ω.

### Simulation

Source: [`ferro/instruments/simulated.py`](../ferro/instruments/simulated.py)

The fakes sit **below** the drivers. `SimLockinTransport` implements the transport
contract and answers `SEN`, `XY` and the rest as a 5302 would — starting in the lab
manual's set-up, and taking new values from `SEN 21`-style commands — so the real
parsing, scaling and setting code runs. `SimSR830Transport` does the same with the
SR830's commands, in volts. `SimModbusInstrument` stands in for `minimalmodbus.Instrument`, so the real
`decode_temperature` runs. One shared `SimulatedSample` keeps all three instruments
agreeing on the temperature. `lockin_transport` and `dmm_transport` pick the fake that
matches the selected model.

## 5. DAQ

Source: [`ferro/acquisition.py`](../ferro/acquisition.py)

### Threads

| Thread | Job | May block? |
|---|---|---|
| GUI (Qt) | draw, respond to clicks | **Never** — the window would freeze |
| Acquisition | all instrument I/O | Yes, for seconds |

They communicate three ways. **Callbacks** (`on_sample`, `on_log`, `on_status`,
`on_recording`), which the GUI wraps in Qt signals so they queue safely across threads.
**Stop**, a `threading.Event`. And **Record on/off**, a request variable under
`_req_lock` that the loop picks up at the top of its next pass — only the acquisition
thread ever opens or closes the data file.

### Opening instruments

`open_lockin` picks the driver for the selected model, then branches: simulated, SR830
(GPIB with LF terminators, nothing to probe), serial, or GPIB. The GPIB path, used by
the 5302, runs the terminator probe with a short timeout and **no
retries**, so a wrong pair fails fast; caches the winning pair per resource; then
restores the full timeout and turns retries on. `open_pid` and `open_dmm` are simpler;
`open_dmm` gives the Keithley 199 its CR LF terminators.

### `InstrumentSlot`: one state machine per instrument

```
 off ──get() opens it──► ok ◄── a read succeeds
  ▲                      │
  │ 3 failures: close,   │ a read fails
  │ reopen after 5 s     ▼
  └────────────────── error
```

`get()` opens the device lazily, and while the 5-second backoff runs it raises "waiting
to reconnect" instead. `failed()` counts failures, and on the third closes the device and
schedules a reopen.

The two thermometer slots, controller and multimeter, also have `discard_after_open`
(`DISCARD_TEMPERATURES_AFTER_OPEN`, 3). Every successful open, at the start of a run or
on a reconnect, resets `to_discard` to it, and that many readings are thrown away before
any is trusted.

### `_read`: the wrapper around every instrument call

- It times the call — the source of the "falling behind" message's numbers.
- On the **first** failure it logs one warning. It is edge-triggered: one message when
  something breaks, not one per sample.
- When a device recovers it logs "answering again after N s".
- On failure it returns `None`, and the caller records NaN plus a flag.
- While a slot still has readings to discard it returns `DISCARDED`: the instrument
  answered (its light stays green), but the caller records NaN with flag 16, not the
  error flag.

### `_run`: the clock

Readings follow an **absolute schedule**, `next_tick = t0 + n × interval`, so sleep errors
never accumulate into drift. With a 0.2 s interval and a 0.15 s reading, the loop sleeps
0.05 s. If a reading takes 2.1 s, `delay` comes out negative, so the loop resets the
schedule to *now* rather than firing a burst of catch-up reads, and warns at most every
30 s.

It waits with `_stop.wait(delay)` rather than `sleep`, so Stop wakes it instantly. The
body sits inside `try/except` so one bad sample can't kill the thread, and `finally`
closes the file and instruments however the loop ends.

### `_sample`: building one row

It reads the controller, then the multimeter if enabled, then the lock-in, into a dict
whose keys are the file's columns. A failure becomes NaN plus a **flag bit**:

| Bit | Value | Meaning |
|---|---|---|
| 0 | 1 | lock-in overload |
| 1 | 2 | lock-in error |
| 2 | 4 | controller error |
| 3 | 8 | multimeter error |
| 4 | 16 | temperature discarded just after connecting |

The bits add, so `flags = 6` means the lock-in and the controller both failed that
sample. `T_C` then comes from whichever temperature source is selected, the ramp
direction updates, and the over-temperature alarm fires once, as the limit is crossed.

### Ramp direction: `DirectionTracker`

Source: [`ferro/analysis.py`](../ferro/analysis.py)

The rig's temperature readings wobble by degrees around the ramp, whether from the
heater cycling or a noisy probe. A local slope follows every swing — the first version of this tracker used one and flipped
between heating and cooling on each. So the tracker does two things instead:

1. **Average** the temperature over the last 120 s. Swings much faster cancel out.
2. **Turn only at a turning point.** While heating it remembers the highest average
   reached, and calls the ramp cooling once the average is **3 °C** below that peak;
   the mirror image while cooling. A wobble smaller than the band never turns it,
   however steep.

| State | Becomes | When |
|---|---|---|
| 0, not yet known | heating / cooling | the average has moved 3 °C from where it started |
| heating | cooling | the average is 3 °C below the highest it reached |
| cooling | heating | the average is 3 °C above the lowest it reached |

A turn is recognised a minute or two after the real extreme. At that moment
`just_turned` is set and `turn_time_s` / `turn_temp_c` give the extreme, so `_sample`
annotates the file (`# Ramp turned to cooling at 150.1 °C, t = 7512 s …`) and the
window recolours the points since then. The rows already written keep the old label.

On synthetic 25 → 150 → 25 °C runs at 1–10 °C/min with ±5 °C swings of period 5–120 s it
turned exactly once every time, within 4 s of the true peak; the old slope tracker
turned hundreds of times once the swings were 30 s or slower. `segment` counts the
turns; `slope_c_per_min`, for the display only, is a least-squares slope of the averaged
temperature over the last 120 s.

### Watching settings

`_watch_lockin` runs every sample and costs nothing, since SEN, EX and overload arrive
with each reading. `_poll_settings` runs every 60 s: the lock-in's full `settings()`
(the reference, oscillator, filters, reserve, input and phase, and on the SR830 also
coupling, grounding, slope and displays — `LOCKIN_WATCHED` lists what is compared) and the controller's mode and run
state, which each need extra exchanges. Any change is **annotated** — logged, and
written into the data file as `# HH:MM:SS …` — so the file explains itself. Each poll
also goes to `on_lockin`, which fills the window's Lock-in tab.

### Changing lock-in settings during a run

The window never talks to an instrument the acquisition thread has open: two threads
on one GPIB device would interleave their bytes. So the Lock-in tab calls
`set_lockin(changes)`, which only stores the request under `_req_lock`, like
`set_recording`. At the top of its next pass the loop's `_handle_lockin_request` sends
it with the driver's `apply()`, annotates what was sent (`Lock-in set from PyFERRO:
filter FLAT (FLT 0)`), and brings the next poll forward, so the read-back — and any
"changed to" line — follows at once. The file therefore shows both what was asked for
and what took effect. `apply()` checks every value before sending the first command,
and sends the time constant before the reserve, since a FAST time constant forces MIN
reserve. When no run is active the tab opens its own connection instead, like Test.

### Recording

Source: [`ferro/datafile.py`](../ferro/datafile.py)

`_handle_record_request` picks up the Record button. `_open_writer` creates a unique path
and writes a header including the instrument settings read at that moment. `_maybe_write`
applies the ΔT gate. `DataWriter.write` writes a tab-separated row and **flushes and
fsyncs every row**, so a power cut loses at most one. `_close_writer` closes the file and
copies the session log beside it.

## 6. One sample, traced

A 0.2 s interval with both instruments healthy:

| t (s) | Layer | What happens | On the wire |
|---|---|---|---|
| 0.000 | DAQ | `_run` tick → `_read("pid")` | |
| | Transport | minimalmodbus → pyserial, ~18 ms out | `:010310000002EA␍␊` |
| | Transport | reply, ~20 ms + controller | `:01030405DC0640D1␍␊` |
| | Driver | `[1500, 1600]` → PV 150.0 °C, SV 160.0 °C | |
| ≈ 0.05 | DAQ | `_read("lockin")` → `Lockin5302.read()` | |
| | Transport | sensitivity, then 50 ms gap | `SEN␍` → `17␍` |
| | Transport | expand, then 50 ms gap | `EX␍` → `0␍` |
| | Transport | data, then 50 ms gap | `XY␍` → `5000,-2500␍` |
| | Driver | X 25 mV, Y −12.5 mV at 50 mV full scale | |
| ≈ 0.22 | DAQ | row built, direction updated, `on_sample` → Qt queue → plots; row written and fsynced | |
| | DAQ | `next_tick` was 0.2 and has passed → no sleep this time | |

> The lock-in's three 50 ms gaps alone take 150 ms. **A 0.2 s interval is just below
> what this rig can sustain** — 0.25 to 0.3 s is the realistic floor.

## 7. Check yourself

<details><summary>The lock-in returns <code>12000,300</code> with SEN = 15, EX = 0. What is X, and which flag is set?</summary>

12000/10000 × 10 mV = **12 mV**. 12000 counts is the overload threshold, so flag value
**1**.
</details>

<details><summary>SEN = 17, EX = 1, and <code>XY</code> answers <code>4000,4000</code>. What are X and Y?</summary>

Full scale is 50 mV. X = 4000/10000 × 50 mV ÷ 10 = **2 mV**. Expand is X only, so
Y = 4000/10000 × 50 mV = **20 mV**.
</details>

<details><summary>Why does <code>SerialTransport</code> never need <code>drain_replies</code>?</summary>

Every serial exchange ends at a prompt, `*` or `?`, so a reply can't spill into the next
exchange.
</details>

<details><summary>The CND3's PV word is <code>FF38</code>. What temperature is that?</summary>

65336 − 65536 = −200 → **−20.0 °C**.
</details>

<details><summary>At a 1 s interval, the RS-485 wires come loose for 20 s. What appears in the log and the file?</summary>

One warning when it breaks. Rows get PV = NaN with flag **4**. On the third failure the
slot closes and retries roughly every 5 s, logging each attempt. When the wires
reconnect: "answering again after ~20 s".
</details>

<details><summary>The loop is sleeping between samples. Why does Stop still respond immediately?</summary>

It waits with `_stop.wait(delay)`, which returns the moment the Stop event is set.
</details>

<details><summary>What goes wrong if the GUI thread calls <code>Lockin5302.read()</code> directly?</summary>

The window freezes for every instrument delay — several seconds on a timeout.
</details>

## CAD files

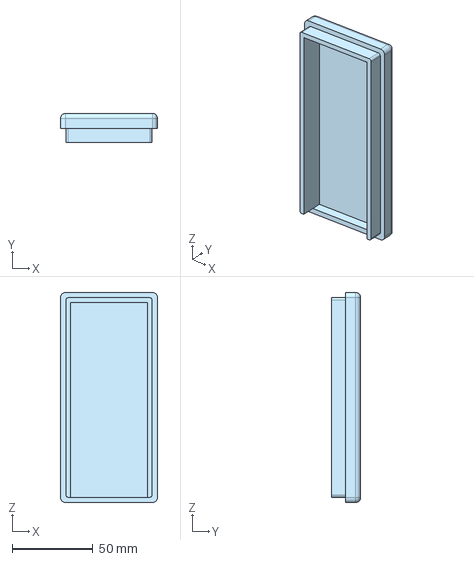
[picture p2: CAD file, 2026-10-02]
cadfiles/lid.step
60.0 x 18.0 x 130.0 mm

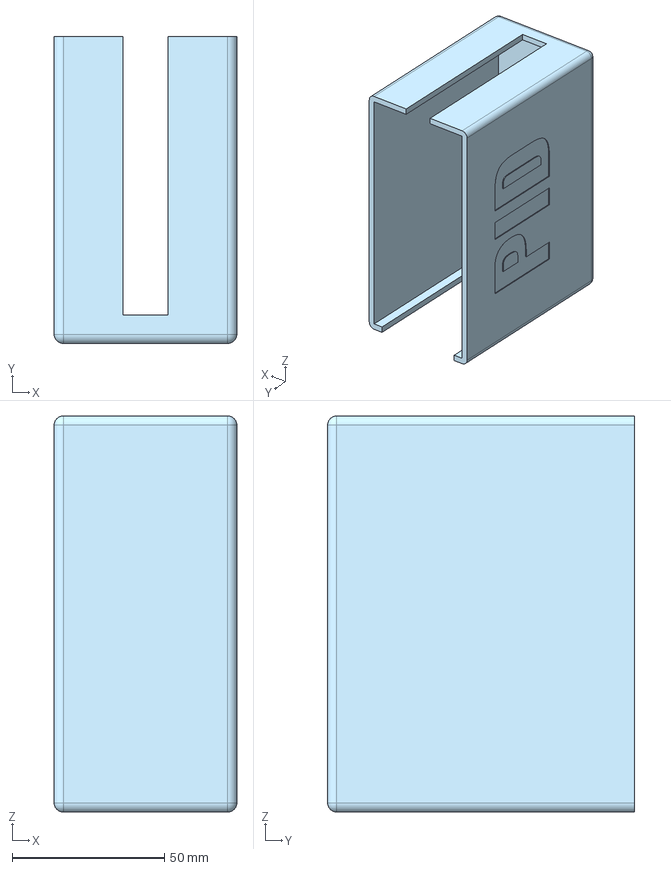
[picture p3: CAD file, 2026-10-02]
cadfiles/case.step
60.0 x 100.7 x 130.0 mm

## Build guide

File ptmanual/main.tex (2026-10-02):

% !TEX program = lualatex
% =============================================================================
%  Phase Transitions: Metal--Insulator transition in VO2 and
%  Ferroelectric transition in BaTiO3
%  Advanced Laboratory, Dept. of Physics & Astronomy, Stony Brook University
%
%  Accessible LaTeX edition: main.tex is untagged, main-tagged.tex is tagged PDF/UA-2.
%  Compile with lualatex (>= TeX Live 2024).  Run twice for cross-references.
% =============================================================================
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
% tagging=off is silently overridden.
\def\metadatakeys{lang = en-US, pdfversion = 2.0,
  testphase = {phase-III, math, graphic, table, firstaid}}
\ifdefined\tagged
  \edef\metadatakeys{\metadatakeys, pdfstandard = ua-2}
\else
  \edef\metadatakeys{\metadatakeys, tagging = off}
\fi
\expandafter\DocumentMetadata\expandafter{\metadatakeys}

\documentclass[11pt,a4paper]{article}

% ---- Fonts -------------------------------------------------------------------
% LuaLaTeX reads UTF-8 and loads Latin Modern (OpenType) by itself; unicode-math
% sets the maths in Latin Modern Math, so formulas carry real Unicode characters.
\usepackage{microtype}

% ---- Page geometry -----------------------------------------------------------
\usepackage[margin=2.5cm,headheight=14pt]{geometry}

% ---- Maths -------------------------------------------------------------------
\usepackage{amsmath}
\usepackage{unicode-math}   % after amsmath; replaces amssymb
\setmathfont{Latin Modern Math}
\usepackage{siunitx}
\sisetup{separate-uncertainty, range-units=single}
% Typeset the percent sign as text.  A bare % inside maths ends up unescaped in
% luamml's MathML cache file, and commenting out the rest of that line breaks
% the cache when the next pass reads it back.
\DeclareSIUnit{\percent}{\text{\%}}

% ---- Graphics, color, floats ------------------------------------------------
\usepackage{graphicx}
\graphicspath{{figures/}{tikz/}}
\usepackage{xcolor}
\usepackage{float}
% Pack floats more tightly so that a single figure never claims a whole page.
\renewcommand{\topfraction}{0.9}
\renewcommand{\bottomfraction}{0.8}
\renewcommand{\textfraction}{0.07}
\renewcommand{\floatpagefraction}{0.75}
\setcounter{topnumber}{3}
\setcounter{bottomnumber}{2}
\setcounter{totalnumber}{4}
\usepackage{booktabs}

% ---- Links -------------------------------------------------------------------
\usepackage{hyperref}
\hypersetup{
  colorlinks = true,
  linkcolor  = [rgb]{0.00,0.25,0.60},
  urlcolor   = [rgb]{0.00,0.35,0.30},
  citecolor  = [rgb]{0.00,0.25,0.60},
  pdftitle   = {Phase Transitions: Metal-Insulator Transition in VO2 and
                Ferroelectric Transition in BaTiO3},
  pdfauthor  = {Michael Gurvitch and Laszlo Mihaly},
  pdfsubject = {Advanced Laboratory write-up, Stony Brook University},
  pdfkeywords= {phase transition, metal-insulator transition, vanadium dioxide,
                ferroelectricity, barium titanate, lock-in amplifier,
                four-probe method, Landau theory},
}
\usepackage{url}

% ---- Convenience macros ------------------------------------------------------
\newcommand{\VOtwo}{VO\textsubscript{2}}
\newcommand{\BTO}{BaTiO\textsubscript{3}}
\newcommand{\Rs}{R_S}
\newcommand{\degC}{\si{\degreeCelsius}}

% \tikzfig{<file base>}{<alt text>}  -- include a standalone TikZ figure that
% has been pre-compiled to tikz/<base>.pdf, together with its alternative text.
% The optional argument holds graphicx keys (default: full text width).
\newcommand{\tikzfig}[3][width=\linewidth]{%
  }

% \photo{<file>}{<alt text>} -- a raster image plus its alternative text.
\newcommand{\photo}[3][width=0.7\linewidth]{%
  }

% A boxed safety / practical note, announced in words as well as by its frame.
\newcommand{\notebox}[2]{%
  \par\medskip\noindent
  \fbox{\parbox{\dimexpr\linewidth-2\fboxsep-2\fboxrule}{\textbf{#1.} #2}}%
  \par\medskip}

\title{Phase Transitions:\\
       Metal--Insulator Transition in \VOtwo\ and\\
       Ferroelectric Transition in \BTO}
\author{Advanced Laboratory\\
        Department of Physics \& Astronomy\\
        Stony Brook University}
\date{Write-up version of September 2026\\[2pt]
      \small Sections on ferroelectricity in \BTO\ by Laszlo Mihaly and, in
      part, Michael Gurvitch; sections on phase-transition theory and the
      metal--insulator transition in \VOtwo\ by Michael Gurvitch.}

\begin{document}

\maketitle
\thispagestyle{empty}

\clearpage
\tableofcontents
\clearpage

% =============================================================================
\section*{Pre-experiment and mid-experiment evaluation sheet}
\addcontentsline{toc}{section}{Pre-experiment and mid-experiment evaluation sheet}
% =============================================================================

You must meet with a staff member for the experiment you are doing before
beginning an experiment and before the lab period indicated in the middle of the
experiment for an evaluation of your preparation and your progress to date. This
form must be signed and dated by the staff member to indicate you have done the
required work to date. It must be attached as the first page of your report. You
will lose one grade point from your report grade for each section of this form
that is not properly signed on time. If this is your first experiment you should
also be prepared to demonstrate you have read and understood the information on
log books in the course notes.

\bigskip
\noindent Student name\ \hrulefill

\medskip
\noindent Partner name\ \hrulefill

\subsection*{Pre-lab discussion}

Be prepared to demonstrate you have read the background material for this
experiment (most of this material is contained in this write-up, but also in
cited references; it includes theory described in Appendix~\ref{app:ac}).
Discuss the following questions with the staff:

\begin{enumerate}
  \item Describe what we mean by phase transitions; give some examples; what is
        the difference between phase transitions of the first and second kind?
        Experimentally, in this lab, how can we tell which transition it is?
  \item Give a general description of a metal--insulator transition; what
        happens to the electronic spectrum of a solid when this transition takes
        place? What is the most direct manifestation of this transition, and how
        can it be detected? Is this transition taking place all at once in the
        whole sample, or not (explain)?
  \item Explain what ferroelectricity is and what the mechanism for it in \BTO\
        is.
  \item What does a PID controller do? Be specific about its principle of
        operation.
  \item What is the general principle of operation of a lock-in amplifier?
\end{enumerate}

\bigskip
\noindent Completed before first period for the experiment?\qquad Yes\,/\,No

\bigskip
\noindent Staff comments\ \hrulefill

\bigskip
\noindent Staff signature\ \hrulefill\ Date\ \hrulefill

\clearpage
% =============================================================================
\section{How to prepare for the measurement}
% =============================================================================

This write-up contains a lot of material. You should study parts of it before
coming to the lab, and read and study the entire text throughout the course of
this experiment.

\notebox{Note}{A big chunk of this manual is in the Appendices, so do not treat
them as secondary-importance material.}

You should also supplement this write-up by looking up and reading some of the
books/articles/websites from the list of references. We propose that you start
in the following order:

\textbf{First read Sections \ref{sec:prepare}--\ref{sec:report}}, which will give you an
overview of this lab. Then spend some time learning how to use the lock-in
amplifier. Your first task will be to master preliminary practice measurements
of resistance and capacitance. During the first two periods of the lab work,
concentrate on \textbf{Section~\ref{sec:techniques}} of this write-up entitled
``Measurement techniques'' and study \textbf{Appendices \ref{app:ac} and
\ref{app:fourprobe}}. Read the equipment
manual for the lock-in amplifier and Ref.~\cite{ref:lockin}; study the
principle of its operation. Simultaneously, study the instrument hands-on:
connect a circuit and first measure a \underline{known} resistor, and then a \underline{known}
capacitor, using the lock-in.

Once you get familiarized with using the lock-in, read about the rest of the
experimental set-up, which is described in Sections
\ref{sec:apparatus}--\ref{sec:advice}. Then you should start reading more of a
physics theory, which is to be found mainly in a large
Appendix~\ref{app:physics}. The physics of phase transitions is not trivial,
and it will take time to ``digest'' and understand it.

From the beginning, keep good records in your notebook. All electrical circuits
that you will build, simple calculations which accompany construction of these
circuits, such as estimates of the measuring current, choice of a limiting
resistor, calculations of resistance and capacitance, sketches of samples or
experimental apparatus, details of sample preparation and geometry, all notes
concerning physics, and all your calculations of physical quantities should be
recorded in the notebook. Short comments you may write should be
understandable, in case you or someone else will later examine your records. The actual experimental
data will be stored in the computer and need not be in the notebook.

% =============================================================================
\section{Goals of the experiment}\label{sec:prepare}
% =============================================================================

\begin{itemize}
  \item Understand experimental techniques used in this lab, including the
        principle and practical operation of a lock-in amplifier when measuring
        resistance and capacitance, the four-probe method, temperature control.
  \item Learn to handle and prepare samples; learn how to quickly check samples
        before they are used in lengthy measurements.
  \item Study the metal--insulator transition in \VOtwo.
  \item Study the ferroelectric transition in \BTO.
  \item Learn basic physics associated with phase transitions and apply it to
        interpreting specific experiments at hand.
  \item We do not just do measurements for the sake of measurements. An
        experiment should lead to some conclusions and it should culminate and
        result in learning of some ``new'' physics (new to us in this lab;
        perhaps not new to the physics community). Therefore it is very
        important to use your data to extract some meaningful physical results:
        namely, estimates of
        microscopic or theoretical quantities which enhance our quantitative
        understanding of the studied phenomena. You will do so for both phase
        transitions studied in this lab.
\end{itemize}

% =============================================================================
\section{Experimental set-up}
% =============================================================================

\begin{itemize}
  \item Sample chamber with four electric leads.
  \item Temperature controller.
  \item Lock-in amplifier (SRS SR830) to measure the samples.
  \item HP 34401A multimeter (not needed for the standard measurement).
  \item Computer (username \texttt{LabStudent}, password \texttt{PhaseTransition}).
  \item Decade resistance box, additional resistors, capacitors, BNC cables etc.
\end{itemize}

The Omega CN08D3-SR-2U-CM-AC temperature controller controls the heater
and can be programmed from its front panel, connected to the computer via RS-485.
The lock-in amplifier is connected to the computer by the
IEEE~488 (GPIB) interface and PyFERRO displays and records
all measurements in real time.

\begin{figure}[htbp]
  \centering
  \tikzfig[width=\linewidth]{fig-daq-wiring}{%
    Wiring diagram of the experiment. At the top left a box labeled Lock-in
    amplifier, SRS SR830, has measuring-input and oscillator-output
    terminals; the oscillator drives the sample through resistor R-zero and the
    measuring input sits across the sample. Below it a dashed box marks the
    sample chamber, containing the sample capacitor, a heater winding and a
    thermocouple. The thermocouple runs to the PID controller box, an Omega CN08D3, which
    lists probe input terminals 10, 11 and 12, output OUT1 on terminals 8 and 9,
    and RS-485 on terminals 13 (D minus) and 14 (D plus). OUT1 switches a
    solid-state relay that powers the heater from AC mains. On the right, the
    lock-in reaches the lab PC over GPIB at address 8 through an NI adapter,
    and the controller reaches it over RS-485 through a Dtech USB converter.}
  \caption{Instrument connections for the temperature-dependent measurement.}
  \label{fig:daqwiring}
\end{figure}

% =============================================================================
\section{Principle of the measurement and an overview of data analysis}
% =============================================================================

Details on these subjects will be found in the rest of this write-up; and you
know what they say: \textit{the devil is in the details}. Here is the \textbf{brief summary:}

You will be studying two different phase transitions, both taking place as a
function of temperature: a metal--insulator transition in vanadium dioxide
(\VOtwo) and a ferroelectric transition in barium titanate (\BTO). Read
\textbf{Appendix~\ref{app:physics}} where the physics of phase transitions is reviewed
and detailed.

The sample is placed in a temperature-controlled chamber. The temperature is
slowly changed, first rising, and then cooling down, while either resistance
$R$ (in \VOtwo) or capacitance $C$ (with \BTO\ serving as dielectric) is
measured and data is recorded. The temperature will change between room
temperature and about \SI{100}{\degreeCelsius} in the case of \VOtwo, and
between room temperature and about \SI{150}{\degreeCelsius} in the case of
\BTO. The measurement of $R$ and $C$ is performed in an AC mode using a lock-in
amplifier, which is described below in Section~\ref{sec:techniques} and in
Appendix~\ref{app:ac}.

What will you be able to learn from these measurements? In the case of the
resistive \VOtwo\ data, you will be able to make conclusions concerning the
nature and order of a phase transition, including estimates of the
metal--insulator transition temperature, of the percolation transition
temperature, of the coercive temperature. You will also be able to analyze the
data to extract the gap of \VOtwo\ in a semiconducting phase and to
estimate absolute resistivities of the two phases.

In the case of a capacitance measurement, \BTO\ will be the dielectric inside a
capacitor. In a parallel-plate capacitor,
\begin{equation}
  C = \frac{\varepsilon A}{d} = \frac{\varepsilon_0 k A}{d},
\end{equation}
where $A$ is the area of the capacitor, $d$ is the distance between the plates,
$\varepsilon$ is the dielectric constant, $\varepsilon_0$ is a constant called
the permittivity of free space, and $k$ is the relative dielectric constant. We
will be interested in finding $k$ as a function of temperature. It will not be
possible to exactly measure $A$ and $d$ in the type of samples you will have,
but they can be roughly estimated. So, by measuring $C$ (which is measured quite
precisely), you will be able to estimate $k$ to within about a factor of two
accuracy, the uncertainty coming almost entirely from a limited ability here to
evaluate capacitor geometry. At the same time, you can certainly follow how $k$
will change with temperature with the full precision of the capacitance
measurement. This $T$-dependence will pinpoint the temperature of a phase
transition, $T_C$. Combined, these data will allow a calculation of microscopic parameters
of a ferroelectric transition as outlined in Appendix~\ref{app:physics}. At the
end, you will be able to estimate an interesting microscopic quantity: the very
small distance by which atoms shift in the lattice of \BTO\ in a ferroelectric
transition. The ability to estimate such a quantity is what makes this
experiment especially interesting.

\subsection*{List of physical quantities which you will be expected to extract,
calculate and estimate from your data}

\noindent(Some of these can be measured rather precisely; others only roughly
estimated.)

\paragraph{In \VOtwo:}
\begin{itemize}
  \item The semiconducting gap $E_g$
  \item The resistance ratio between semiconducting and metallic phases
  \item Absolute resistivities in semiconducting and metallic phases
  \item The value of $T_C$
  \item The coercive temperature $T^{*}$
  \item The temperature of a percolation transition $T_M$
\end{itemize}

\paragraph{In \BTO:}
\begin{itemize}
  \item $T_C$
  \item Relative dielectric constant $k$ vs.\ $T$, from about
        \SI{20}{\degreeCelsius} to \SI{150}{\degreeCelsius}
  \item Curie--Weiss law at $T > T_C$ and Curie--Weiss constant $C_{CW}$
  \item The value of a microscopic dipole moment $p$
  \item The effective atomic displacement $x$ responsible for the appearance of
        $p$
  \item The last two quantities can be also calculated for \BTO\ single crystals
        using the literature value of $C_{CW}$
\end{itemize}

% =============================================================================
\section{Looking ahead: what should and should not be included in your Final
         Report}\label{sec:report}
% =============================================================================

Your performance will be judged primarily from the contents of your Final
Report. In it there will be several different (but related) parts:

\begin{itemize}
  \item A physics introduction concerning phase transitions and materials
        which you studied and a physics analysis of your results at the end. To
        get these right, you have to study Appendix~\ref{app:physics} of this
        write-up and related literature.

  \item A description of experimental set-up (including electrical circuit
        diagrams) and experimental techniques that you used (lock-in and how it
        was used; four-probe method), including significant details of how you
        obtained your data. For example, if you are measuring some voltage, but
        your ``final product'' is capacitance, you will need to
        explain in some detail how you proceeded from that voltage to knowing
        that capacitance. This may include phasor diagrams and some formula
        derivations given in Section~\ref{sec:techniques} and
        Appendix~\ref{app:ac}.

  \item Initially you will be measuring \emph{known} resistances and
        capacitances just to learn how to connect the circuits and how to use
        the lock-in amplifier. It is very important to perform such calibrations
        or baseline measurements in order to be sure that later you will be
        measuring your samples correctly. While a detailed description of such
        calibrations may be perfectly appropriate for your mid-lab report, it
        should not take center-stage in the Final Report, except as a short
        mention of the fact that these calibrations were done. You may want to
        report the uncertainty (i.e.\ \% of relative deviation) in the
        measurement of a known $R$ and $C$ (of course, assuming that the values
        of these $R$ and $C$ were known very accurately in the first place). But
        detailed data on such baseline measurements would be out of place; the
        focus of the Final Report should be on measuring real samples which
        exhibit phase transitions.

  \item You will present results of sample measurements, your data, in the form
        of graphs, possibly some tables (but do not list all of the data points
        in long tables --- this is neither necessary nor desirable in the Final
        Report). If you are measuring resistance $R$ and capacitance
        $C$ as a function of temperature $T$, your data may consist of graphs of
        $R(T)$ and $C(T)$.

        Let us discuss this in a little more detail. There exists a notion of
        \emph{raw data}, the data you directly obtain in your measurement,
        directly read off the instruments. And then there is data which was to
        some degree analyzed and organized. For example, you may be measuring
        separate values of voltage $V$ and current $I$, and later you may be
        combining the two when obtaining resistance $R = V/I$. But your interest
        --- and the interest of the reader of your report --- is in that
        resistance $R$, and not in $V$ or $I$. Thus one should use common sense
        when reporting data: probably in this example, separate values of $V$
        and $I$ should not be reported (they can remain in your electronic data
        storage, to be examined if necessary), and $R$ should be reported.
        Likewise, if you are measuring a voltage signal which is being converted
        to a capacitance, do not report those voltages; report capacitance
        directly. You may however mention the range of the voltage signals
        that you measured in order to tell your reader something meaningful
        about the quality of your data.

  \item The data should be presented with uncertainties, which not only should
        be included, but accompanied with a brief explanation of how they were
        obtained or estimated. If a calculation is involved, the error must be
        propagated from the raw data to the calculated quantity. If curve
        fitting is involved, the uncertainty will come out of the fitting
        routine. You need also to point out which uncertainties are more
        significant, and which can be ignored; in this lab this last comment
        will be particularly relevant, as some of the uncertainties will far
        exceed others.

  \item There will be data analysis: corrections which you introduced to your
        data, extraction of physical parameters of interest. And at the end
        there will be some conclusions based on your results. You will need to
        study this write-up and references in order to ``connect the dots'', to
        make your experiments meaningful. When applicable, you will compare your
        results to the published results. Finding relevant publications by doing
        literature searches, reading them, and extracting from these
        publications important parameters, is part of a skill of an experimental
        physicist.
\end{itemize}

% =============================================================================
\section{Measurement techniques}\label{sec:techniques}
% =============================================================================

The main instrument you will be using in your measurements in this lab is
called a \emph{lock-in amplifier} ~\cite{ref:lockin}. This wonderful instrument
was invented in the 1950's by a physicist Robert Dicke; it is used extensively
for a variety of measurements in physics experiments and elsewhere.

\begin{figure}[htbp]
  \centering
  \photo[width=0.24\linewidth]{dicke.png}{%
    Black-and-white portrait photograph of the physicist Robert Dicke, seated
    and facing the camera.}
  \caption{Robert Dicke (1916--1997), a famous American physicist who made
    important contributions to the fields of astrophysics, atomic physics,
    cosmology and gravity. He also invented the lock-in amplifier in the 1950s,
    with the first commercial model developed in 1962.}
\end{figure}

The advantage a lock-in gives to an experimentalist is in that it rejects a good
deal of noise, increasing the signal-to-noise ratio and allowing the use of
small currents which will not damage even the most delicate of samples.
Additionally, by virtue of always measuring in an AC mode, it automatically
averages the readout voltage, getting rid of the so-called thermal emf offsets
and DC level drifts which are endemic with DC measurements, even when we are
using the best and most accurate DC voltmeters.

While the lock-in amplifier was invented to measure weak signals in the
presence of large noise, in our measurements we will not be pushing the limits
of its capacity in that regard. Instead, we will be using its ability to
measure signals of different specified phases, as explained below and in
Appendix~\ref{app:ac}. This lab gives you an opportunity to learn about this
important instrument.

The name ``lock-in'' refers to locking to a frequency and to a phase of an AC
signal, and measuring only that part of a signal which is in a specified phase
relationship to the reference. This is a version of the \emph{phase-sensitive
detection} technique. The phase can be continually varied and also changed in
\ang{90} steps.

You should read about lock-in operation in our lock-in manual~\cite{ref:sr830}. Here and in
Appendix~\ref{app:ac} we give a brief general introduction to its operating
principle, and discuss in more detail the two types of measurements we will be
doing in this lab.

\notebox{Review AC circuits first}{If you have not been dealing with AC
circuits lately, this would be a good time to thoroughly review them: read
about AC currents in general, and the phasor method in particular, in your
introductory physics course textbook; some of this is also discussed in
Ref.~\cite{ref:accircuits}. Study this section and Appendix~\ref{app:ac}; it is
essential that you understand this topic in order to do this lab.}

\paragraph{The principle of lock-in measurement} is as follows: the lock-in
contains its own AC voltage source called \emph{oscillator output}, in which you
can adjust the amplitude, and frequency
(adjustable in a wide range from a fraction of \SI{1}{\hertz} to
\SI{100}{\kilo\hertz}). The frequency, once you set it, will be kept with great
precision and stability by a lock-in. The readout is tuned to read only
voltage at this frequency (actually, at a double frequency, but this is
immaterial for our general discussion), all the other frequencies being
filtered out. Moreover, it will \emph{look} into a specified \emph{phase} of
this signal. The exact meaning of this last statement will be explained below
and in Appendix~\ref{app:ac}.

The \emph{measuring input} (actually, there are two of them, A and B, and you
can also hook the instrument up to measure the difference $\mathrm{A}-\mathrm{B}$)
is an AC voltmeter, which will measure rms values, and where the sensitivity of
a readout can be changed according to experimental needs, from several volts to
a few millivolts full scale. It can be connected across different parts of a
circuit: for example, it can be connected across $R$ or across $C$. Let us now
discuss specific measuring arrangements: one for measuring a resistance,
another for measuring a capacitance.

\subsection{How to use lock-in to measure resistance?}

Suppose we want to measure a resistance, which may be changing in the course of
a measurement, for example, as a function of temperature. This will be the case
in our \VOtwo\ measurement in this lab. We may connect the lock-in as shown in
Figure~\ref{fig:lockinR}.

\begin{figure}[htbp]
  \centering
  \tikzfig[width=0.8\linewidth]{fig-lockin-resistance}{%
    Circuit diagram. A box labeled Lock-in amplifier sits at the top, with two
    terminals for the measuring input, across which V-meas appears, and two for
    the oscillator voltage output, which supplies V-zero RMS. From the
    oscillator output a wire runs straight down through the resistor R-zero and
    then through the resistor R-D to the right-hand outer contact of the sample.
    The sample is drawn as a horizontal strip carrying four contacts, labeled
    from left to right I-plus, V-plus, V-minus and I-minus. The two inner
    contacts are connected straight up to the measuring-input terminals; a
    parasitic capacitance C-p, drawn with dashed lines, bridges those two inner
    leads. The return wire leaves the second oscillator terminal, runs down the
    right-hand side, along the bottom of the figure and up the left-hand side to
    the left-hand outer contact of the sample, so the current path forms one
    closed loop through the sample.}
  \caption{Connecting the lock-in amplifier for a four-probe resistance
    measurement. $R_0 = \SI{50}{\ohm}$ is the oscillator's internal output
    resistance, $R_D$ the limiting decade resistor, and $C_p$ the parasitic
    capacitance of the cables. The current enters and leaves through the outer
    contacts $I_{\pm}$; the voltage is measured across the inner contacts
    $V_{\pm}$.}
  \label{fig:lockinR}
\end{figure}

The label under the lock-in's SINE OUT connector shows that the oscillator
circuit has internal resistance $R_0 = \SI{50}{\ohm}$, which is really a part of
the lock-in, but, for clarity, is shown on the diagram above outside of a lock-in
block. It is connected in series with the limiting decade resistance $R_D$ and
the sample. The measuring input of the lock-in is connected across the inner
contacts of the sample.

\paragraph{Let us first discuss the current.}
It is alternating, AC current; we will be always talking about rms values of all
voltages and currents in this discussion. The limiting resistor $R_D$ serves to
limit the current, and to make this current approximately constant. To do so,
$R_D$ should be much greater than the sample resistance $R_{S\,tot}$, which is
the total resistance of a sample between the \emph{outside} current contacts
shown in the figure above, and also includes the resistance of these current
contacts (a contact to a sample may have appreciable resistance, see
Appendix~\ref{app:fourprobe}); it is the total resistance encountered by the
current as it flows through the sample.

The value of $R_{S\,tot}$ will be changing in the course of a measurement, as we
change the sample temperature. Let us say its maximum value is
$R_{S\,tot} = \SI{500}{\kilo\ohm}$, and the minimum value can be neglected
compared to \SI{500}{\kilo\ohm}, which is indeed the case with \VOtwo\ (assuming
contact resistance is not very large). Suppose we decided that we will be
satisfied with keeping current constant to \SI{5}{\percent}, i.e.\ we are not
worried about up to \SI{5}{\percent} possible overall distortion in our
measurement. The maximum and minimum rms currents then will be
$I_{\max} = V_0/(R_0+R_D)$ when $R_{S\,tot}$ is negligible, and
$I_{\min} = V_0/(R_0+R_D+R_{S\,tot})$ when $R_{S\,tot}$ is maximum; here $V_0$
is the rms voltage at the oscillator output. We want to have
\begin{equation}
  \frac{\Delta I}{I_{\min}}
    = \frac{I_{\max}-I_{\min}}{I_{\min}} = 0.05 ,
\end{equation}
or, as it is easy to see, simply $R_{S\,tot}/(R_0+R_D) = 0.05$, or
$R_0 + R_D = R_{S\,tot}/0.05 = \SI{10}{\mega\ohm}$. Compared to this value,
$R_0 = \SI{50}{\ohm}$ can be neglected, and essentially our limiting resistor
$R_D$ should be set at \SI{10}{\mega\ohm} (which, incidentally, is the maximum
resistance which can be set in our decade box). If we use this large limiting
resistor, the current will be equal to
$I = \SI{2}{\volt}/\SI{10}{\mega\ohm} = \SI{0.20}{\micro\ampere}$.

\paragraph{Let us now discuss the voltage signal.}
Small current $I$ will result in a fairly small voltage $I R_S$, especially when
$R_S$ also becomes small. Lock-in can measure small voltages, but below about
the \SI{1}{\milli\volt} level, the precision will suffer. If we want to
increase the current, in the present scheme we will have to sacrifice some
additional accuracy in our overall measurement of $R_S$ over the whole range of
its variation.

The sample has four contacts: two outside contacts for the current and two
inner ones for the voltage. You should read about the four-probe measurement in
Appendix~\ref{app:fourprobe}, and a brief description of this principle should
be given in your Final Report. Be ready to answer this question: what is the
advantage of the four-terminal method over the two-terminal method, and how is
this advantage achieved? The voltage from the inner leads
$V_{\mathrm{meas}}$ (see the figure above) is supplied to the lock-in's
measuring input, where it will be amplified (thus the name lock-in
\emph{amplifier}), and provided for the readout on the front panel and, through
the digitizing interface, to the computer. The resistance between the inner contacts will be found as
$R_S = V_{\mathrm{meas}}/I$. Above, when we were discussing the current, we
considered $R_{S\,tot}$ between the outside current contacts, but now we are
measuring resistance $R_S$ between the inner voltage contacts. The lock-in will
display the RMS value as a DC-level signal.

The maximum voltage $V_{\mathrm{meas}}$ in our example (measuring \VOtwo) is
going to be found at room temperature; it will correspond to the maximum value
of $R_S$. Suppose the maximum $R_S$ is equal to \SI{300}{\kilo\ohm} (note that
we are using here $R_S < R_{S\,tot}$). Then the maximum
\begin{equation}
  V_{\mathrm{meas}} = I R_S
    = (\num{2e-7})\times(\num{3e5}) = \SI{60}{\milli\volt}.
\end{equation}
Such a signal would be quite sufficient, but the trouble is that it will be a
lot lower once $R_S$ decreases at high temperatures, where, above the
semiconductor-to-metal transition (see below), we may get a signal as small as
about \SI{0.1}{\milli\volt}. The lock-in is going to give us poor resolution in
that range. Recall also that, with our proposed numbers, we will have a
distortion in resistance values of about \SI{5}{\percent} over the whole range,
as our current will increase by \SI{5}{\percent} when $R_S$ drops by such a
large factor.

An alternative way of dealing with changing $R_S$ is to measure the current
instead of stabilizing it; it can be best measured by monitoring voltage across
the known limiting resistor. Then we do not need such a large limiting
resistor: instead of being \SI{10}{\mega\ohm} it can be, for example,
\SI{10}{\kilo\ohm}, and the current will be 1000 times higher, i.e.\
\SI{0.200}{\milli\ampere} instead of \SI{0.200}{\micro\ampere}. But we will have
to monitor the current and to use the measured current $I_{\mathrm{meas}}$ in a
calculation of a sample resistance at every point along the way. This can be
done with the use of an additional computer-interfaced voltmeter, and with
a modification of PyFERRO.

\notebox{Do not overdrive the sample}{The current should not be increased
indefinitely; excessive currents can produce self-heating and even damage the
thin-film sample. Do not use currents greater than \SI{1}{\milli\ampere} with
our \VOtwo\ samples.}

\paragraph{So, how is the lock-in measuring resistance?}
The oscillator output, as we said above, provides sinusoidal voltage of rms
value $V_0$ at a fixed stable frequency which we can set at will. The readout is
tuned to read only voltage at this frequency (actually, at a double frequency),
all the other frequencies being filtered out. Additionally, it will read only a
specified phase of this signal. For our resistive measurement we expect that the
specified phase should be zero, as resistor does not produce a phase shift. So,
if we are measuring pure resistance, we should be interested in the
\emph{in-phase} signal (see Appendix~\ref{app:ac}). The circuit and the phasor
diagram of a pure resistor $R_S$ are shown in Figure~\ref{fig:resistorphasor}.

\begin{figure}[htbp]
  \centering
  \tikzfig[width=0.95\linewidth]{fig-resistor-phasor}{%
    On the left, a series circuit: an AC source of RMS voltage V-zero drives a
    current I through three resistors in series, R-zero, R-S and R-D. On the
    right, a phasor diagram with a horizontal in-phase axis and a vertical
    out-of-phase axis. A single heavy arrow lies along the in-phase axis and is
    labeled V-R-S equals I times R-S equals V-zero R-S divided by the sum of
    R-S, R-zero and R-D. A curved arrow to the right of the diagram marks the
    counterclockwise rotation with angular frequency omega.}
  \caption{Circuit and phasor diagram for a purely resistive sample.}
  \label{fig:resistorphasor}
\end{figure}

As always, the phasor should be imagined rotating counterclockwise with
$\omega$; the in-phase direction rotates with it; the projection onto the
horizontal axis is the real signal. The current is determined by the source
voltage $V_0$ applied across all of the resistors. We see that in any other
direction the signal will be smaller than in this in-phase direction. Thus, if
we adjust the phase till we see the \emph{maximum} voltage at the measuring
input, this maximum voltage will correspond to the true value of resistance
according to $R_S = V_{\mathrm{meas}}/I$. Simultaneously, the
\ang{90}-shifted, out-of-phase signal should be zero. It is easier to tune the
out-of-phase signal to zero than to find the true maximum in-phase, because when
measuring the near-zero signal we can increase the sensitivity. So the usual
procedure is to change the phase till one brings out-of-phase signal as close to
zero as possible and then to shift the phase by \ang{90} displaying the in-phase
signal. Further, all of the above should be independent
of frequency $f = \omega/2\pi$. This is what one expects; however, there are
complications.

\paragraph{Complications} arise because, in addition to the resistance, the
circuit contains the so-called \emph{parasitic} or \emph{stray} capacitance
$C_p$. This is the capacitance of shielded cables, etc. In our circuit it is
typically of the order of \SIrange{10}{100}{\pico\farad}. This parasitic
capacitance can be thought of as being plugged in parallel to the sample
resistance $R_S$, as shown in the circuit diagram above where it is drawn in
dashed lines. It will effectively shunt (short out) the resistance, leading to
incorrect, decreased values of $V_{\mathrm{meas}}$.

\paragraph{Solution.}
Recall that lock-in allows you to adjust the oscillator frequency $f$, which of
course implies that reactance $X_C = 1/(2\pi f C_p)$ can be controlled. The
solution is then clear: in order to minimize the detrimental effect of $C_p$ we
need to decrease $f$ as much as possible: at low $f$ the reactance
$1/(2\pi f C_p)$ will be large, and the shunting effect of the parasitic
capacitance will be minimized. On the other hand, using extremely low frequency
$f \sim \SI{1}{\hertz}$ may be difficult, as the lock-in tends to lose
its ability to lock the phase at extremely low frequencies. Additionally, the
so-called flicker or $1/f$ noise increases at low frequencies. But we do not
need to reduce $f$ that much: using $f \approx \SI{50}{\hertz}$ is comfortable
in terms of this phase-locking and achieves what we need. Indeed, at
$f = \SI{50}{\hertz}$, for $C_p = \SI{100}{\pico\farad}$, we find
$X_C = 1/(2\pi f C_p) \approx \SI{30}{\mega\ohm}$, which is more than sufficient
to prevent a decrease in $V_{\mathrm{meas}}$ due to shunting.

\notebox{Practical advice}{Insert a \emph{known} resistor in place of your
sample (preferably, with the value similar to $R_S$) and empirically find the
frequency range at which your measurement agrees with that known resistor
value. This is an example of a \emph{baseline} measurement which is done to
establish the validity of the measurement technique.}

\subsection{How to use the lock-in amplifier to measure the capacitance?}

The sample is now a capacitor; the material we want to study (\BTO) is a
dielectric inside the capacitor. In this measurement we do not need to worry
about additionally limiting the current; the current we are dealing with here
is sufficiently limited by $R_0 = \SI{50}{\ohm}$. Here we will be using lock-in
as a device to measure signals that are \emph{phase shifted} from the phase of
$V_0$ due to the presence of resistors and capacitors in the circuit.
The basic circuit diagram for the capacitance measurement is shown in
Figure~\ref{fig:lockinC}.

\begin{figure}[htbp]
  \centering
  \tikzfig[width=0.8\linewidth]{fig-lockin-capacitance}{%
    Circuit diagram. A box labeled Lock-in amplifier sits at the top, with two
    measuring-input terminals, across which V-meas appears, and two
    oscillator-output terminals supplying V-zero RMS. From one oscillator
    terminal a wire runs down through the resistor R-zero to point 1, the top
    plate of the sample capacitor. The capacitor, marked sample and drawn as two
    plates with a shaded dielectric between them, has terminals numbered 1 and 2
    at the top and 3 and 4 at the bottom; the sample is inserted by connecting
    leads 2 and 4 between points 1 and 3. From point 3 a wire returns down and
    round to the second oscillator terminal. The two measuring-input leads run
    down the left of the figure to points 1 and 3, so the measuring input sits
    across the capacitor, and a parasitic capacitance C-p, drawn with dashed
    lines, is connected in parallel with the sample.}
  \caption{Connecting the lock-in amplifier for a capacitance measurement.
    $R_0 = \SI{50}{\ohm}$ is the built-in internal resistance of the signal
    generator, and $C_p$ is the parasitic capacitance of the empty circuit,
    which acts in parallel with the sample.}
  \label{fig:lockinC}
\end{figure}

As in a resistance measurement described above, the signal is generated by the
lock-in amplifier's internal reference (oscillator) output; in this measurement
we will be setting it at $V_0 = \SI{0.500}{\volt}$, $f = \SI{25}{\kilo\hertz}$.
As before, the built-in internal
resistance of the signal generator is $R_0 = \SI{50}{\ohm}$, and there exists
parasitic capacitance $C_p$ shown in dashed lines; this capacitance can be
thought of as connected in parallel to sample capacitance.

Surprising as it may sound, we will first do the measurement of an \emph{empty}
circuit, without the sample. Later we will insert the sample by connecting
sample leads~2 and~4 between points~1 and~3, as shown in the diagram above. The
purpose of the measurement without the sample is in tuning the lock-in, so as to
make it later correctly measure the sample's capacitance.

First, leaving the sample unconnected, we will tune the lock-in so that it is
in-phase with the oscillator; it will measure $V_0 = \SI{0.500}{\volt}$. We then
change the phase by \ang{90} and look at $V_{\mathrm{meas}}$ while gradually
increasing the sensitivity of the measuring readout. On a sensitive-enough scale
we will see some non-zero signal due to parasitic capacitance of our ``empty''
circuit. We will adjust the phase watching the signal on increasingly more and
more sensitive scales till this out-of-phase signal will be made as close as
possible to zero. So, in other words, we will follow the same procedure as in
measuring resistance, as was described above. See Appendix~\ref{app:ac} for the details of the
phasor diagrams in this case.

Once we zeroed the out-of-phase signal, we will insert the sample, so that
points~2 and~4 are connected to~1 and~3; once we have done that, the out-of-phase
readout from the sample $V_{\mathrm{meas}}$ will appear at the measuring input
and the magnitude of that out-of-phase signal is going to be proportional to the
capacitance of the sample. Indeed, the capacitance of our sample is usually
small, of the order of \SI{100}{\pico\farad}--\SI{1}{\nano\farad}, and so, with
$R_0 = \SI{50}{\ohm}$ and at our chosen frequency, we have $\omega R_0 C \ll 1$.
In this limit the in-phase component of the signal will be very close to the
voltage provided by the signal generator, $V_0$, and the out-of-phase component
will be close to $V_0\,\omega R_0 C$ (see Appendix~\ref{app:ac} for the details).
By measuring the out-of-phase component $V_{\mathrm{meas}}$, knowing $V_0$,
$\omega$ and $R_0$, we can calculate the capacitance of the sample as
\begin{equation}\label{eq:Csimple}
  C = \frac{\delta}{\omega R_0},
  \qquad\text{where}\qquad
  \delta = \frac{|V_{\mathrm{meas}}|}{V_0}.
\end{equation}

\subsection{Lock-in amplifier settings}\label{sec:lockinsettings}

The lab's lock-in amplifier is the Stanford Research Systems SR830 DSP
lock-in (Figure~\ref{fig:frontpanel}). Its standard settings for the
capacitance measurement are:

\begin{center}
\begin{tabular}{@{}ll@{}}
  \toprule
  \textbf{Setting} & \textbf{Value} \\
  \midrule
  Input            & A, AC coupled, shield floating \\
  Sensitivity      & \SI{1}{\volt} \\
  Line notch filters & out \\
  Dynamic reserve  & low noise \\
  Oscillator level & \SI{0.500}{\volt} initially \\
  Oscillator frequency & \SI{25}{\kilo\hertz} \\
  Reference phase  & tuned (see below) \\
  Reference        & internal \\
  Oscillator out   & SINE OUT to input A (BNC cable) \\
  Time constant    & \SI{300}{\milli\second}, \SI{12}{\deci\bel}/octave \\
  Displays         & X on channel one, Y on channel two \\
  \bottomrule
\end{tabular}
\end{center}

\paragraph{Setting the SRS SR830.}
Table~\ref{tab:lockinsr830} gives the same settings in more detail: where to
find each one on the front panel, and the equivalent GPIB command. A command
followed by a question mark (\texttt{SENS?}) makes the lock-in reply with the
current value, which is how PyFERRO reads these settings back and records them
in the data-file header. Most of the table is the SR830's own standard set-up,
which it returns to if you hold down the Setup key while switching it on; then
only the frequency, the level and the time constant need changing. PyFERRO can
also send the whole table (Appendix~\ref{app:pyferro}, Lock-in tab).

\notebox{Oscillator resistance and signal size}{The SR830's sine output has an
output resistance of $R_0 = \SI{50}{\ohm}$ (marked under the SINE OUT
connector). The lock-in's least sensitive range is \SI{1}{\volt}, and the
in-phase signal is close to the oscillator level $V_0$, so $V_0$ must stay
below \SI{1}{\volt}; at $V_0 = \SI{0.500}{\volt}$ it is half of full scale.
The out-of-phase signal is then small: for \SI{100}{\pico\farad} at
\SI{25}{\kilo\hertz}, $V_{\mathrm{meas}} = V_0\,\omega R_0 C \approx
\SI{0.4}{\milli\volt}$. Read it with the channel-two Expand (below). A known
resistor $R_s$ in series with SINE OUT raises the signal in proportion; then
use $R_0 = \SI{50}{\ohm} + R_s$, and check that $\omega R_0 C$ stays well
below~1 or use the exact formula of Appendix~\ref{app:ac}.}

\begin{table}[htbp]
  \centering
  \small
  \begin{tabular}{@{}p{2.3cm}p{2.3cm}p{7.6cm}p{2.1cm}@{}}
    \toprule
    \textbf{Setting} & \textbf{Value} & \textbf{How to set it on the front panel}
      & \textbf{GPIB} \\
    \midrule
    Reference & internal
      & Press Source, in the REFERENCE section at the right, until INTERNAL is lit.
      & \texttt{FMOD 1} \\
    Oscillator frequency & \SI{25.000}{\kilo\hertz}
      & Press Freq and turn the knob; the REFERENCE display shows the frequency.
      & \texttt{FREQ 25000} \\
    Oscillator level & \SI{0.500}{\volt}
      & Press Ampl and turn the knob.
      & \texttt{SLVL 0.5} \\
    Signal input & A
      & Cable to the A/I input. Press Input, in the SIGNAL INPUT section at the
        lower left, until A is lit.
      & \texttt{ISRC 0} \\
    Coupling & AC
      & Press Couple until AC is lit.
      & \texttt{ICPL 0} \\
    Grounding & float
      & Press Ground until FLOAT is lit.
      & \texttt{IGND 0} \\
    Line notch filters & out
      & Press Notch, in the FILTERS section, until neither LINE nor 2xLINE is lit.
      & \texttt{ILIN 0} \\
    Sensitivity & \SI{1}{\volt}
      & The arrow keys in the SENSITIVITY section; the up arrow moves to a larger
        full scale (less sensitive).
      & \texttt{SENS 26} \\
    Dynamic reserve & low noise
      & Press Reserve, in the RESERVE section, until LOW NOISE is lit.
      & \texttt{RMOD 2} \\
    Time constant & \SI{300}{\milli\second}
      & The arrow keys in the TIME CONSTANT section.
      & \texttt{OFLT 9} \\
    Filter slope & \SI{12}{\deci\bel}/oct
      & Press Slope/Oct, in the TIME CONSTANT section, until 12 dB is lit.
      & \texttt{OFSL 1} \\
    Offset and expand & off
      & Under each display: OFFSET On/Off until the offset is off, and Expand
        until neither x10 nor x100 is lit.
      & \texttt{OEXP 1,0,0} (and 2, 3) \\
    Displays & X and Y
      & Press Display under each display until X (channel one) and Y (channel two)
        are lit.
      & \texttt{DDEF 1,0,0}, \texttt{DDEF 2,0,0} \\
    Reference phase & $Y = 0$ with the sample disconnected
      & Press Phase in the AUTO section (Auto Phase); repeat once the outputs
        have settled. For fine tuning, press Phase in the REFERENCE section and
        turn the knob.
      & \texttt{APHS} \\
    \bottomrule
  \end{tabular}
  \caption{SRS SR830 settings for the capacitance measurement. The GPIB
    commands are from chapter~5 of the SR830 manual~\cite{ref:sr830};
    \texttt{SENS 26} and \texttt{OFLT 9} are positions in its tables of
    sensitivities (\SI{2}{\nano\volt} to \SI{1}{\volt}) and time constants
    (\SI{10}{\micro\second} to \SI{30}{\kilo\second}).}
  \label{tab:lockinsr830}
\end{table}

The SR830 is a dual-phase lock-in: it shows the in-phase signal as $X$ and the
out-of-phase signal as $Y$ at the same time. Tune the phase with the sample
disconnected until $Y$ is as close to zero as possible (Auto Phase does this),
then connect the sample and read $V_{\mathrm{meas}}$ from $Y$.

Before measuring the sample, we do a practice run by measuring the capacitance
of a piece of BNC cable. See Appendix~\ref{app:ac} for the relevant phasor
diagrams.

\begin{figure}[htbp]
  \centering
  \photo[width=\linewidth]{sr830-front-panel.jpg}{%
  Photograph of the front panel of the Stanford Research Systems SR830 DSP
  lock-in amplifier. From the left: the TIME CONSTANT and SENSITIVITY arrow
  keys, with the SIGNAL INPUT, RESERVE and FILTERS sections below them and the
  A/I and B input connectors at the bottom; the channel-one and channel-two
  displays, each with Display, Ratio and Expand keys, OFFSET keys and an output
  connector; the AUTO, SETUP and INTERFACE keys; and on the right the
  REFERENCE display, the Phase, Freq, Ampl and Harm keys, the +90 and -90
  degree keys, the setting knob, and the REF IN and SINE OUT connectors.}
  \caption{The SRS SR830 DSP lock-in amplifier. Photo: Stanford Research Systems.}
  \label{fig:frontpanel}
\end{figure}

First, check the signal generated by the lock-in amplifier's internal
oscillator. Connect one end of a BNC cable to SINE OUT and the other end to
the A/I input, and set the lock-in as in Table~\ref{tab:lockinsr830}. Press
Phase in the REFERENCE section and turn the knob to set the reference phase
to \ang{0.00}. Channel one shows the in-phase component X and channel two the
out-of-phase component Y. If most of the signal appears in X, its reading
should be close to the oscillator setting of \SI{0.500}{\volt}.

We are interested in the out-of-phase component Y. Ideally, Y should
be zero after the phase has been correctly adjusted. However, the
electronics inside the lock-in amplifier can introduce a small phase
error, so Y may initially have a small but nonzero value.

The lock-in amplifier provides an automatic way to correct this phase
error. Press Phase in the AUTO section to run Auto Phase. Wait a few
seconds for the readings to settle. The in-phase component X should then
be maximized, while the out-of-phase component Y should be close to zero.

Upon closer inspection, you may find that Auto Phase has left a small
out-of-phase signal, too small to read on the \SI{1}{\volt} range. Keep the
sensitivity at \SI{1}{\volt} and press Expand under channel two once (x10) or
twice (x100). The expand does not change the value shown for Y: it adds
digits to it, so a signal of a fraction of a millivolt can be read. Press
Phase in the REFERENCE section and turn the knob until Y is as close to zero
as possible. If channel two's display shows OVLD, reduce the expand. Do not reduce the \SI{1}{\volt} sensitivity setting while the
oscillator is connected directly to the input: X would then be beyond full
scale.

Now that the out-of-phase signal has been brought as close to zero as
possible, keep the sensitivity at \SI{1}{\volt}. Insert a BNC ``T''
connector into the line and connect another BNC cable. The added cable
will produce a nonzero out-of-phase signal $V_{\mathrm{meas}}$, which
you can read from Y. Calculate its capacitance using
$C = |V_{\mathrm{meas}}|/(V_0\omega R_0)$, where
$V_0 = \SI{0.500}{\volt}$,
$\omega = \SI{1.57e5}{\per\second}$, and
$R_0 = \SI{50}{\ohm}$.
Measure the length of the cable, then repeat the measurement with a
longer cable. Turn the expand off again when you are done: PyFERRO notes
an expand in the data file.

\notebox{Question}{In round numbers, what is the capacitance of one foot of BNC
cable?}

% =============================================================================
\section{The rest of the experimental apparatus in detail}\label{sec:apparatus}
% =============================================================================

\subsection{Sample chamber}

A photograph of the sample chamber is shown in Figure~\ref{fig:chamber}. There
are four wires reaching the inside of the chamber, ``red'' and ``black'' pairs.
The sample will be either a film of \VOtwo\ with four resistive leads, or a
capacitor with \BTO\ requiring only two leads attached to its plates. If two
students do the measurement, it is recommended that each one of them mounts
their own sample and evaluates the data independently. However, \VOtwo\ samples are
fragile, and a staff member should be asked to mount them in the chamber, at
least initially.

\begin{figure}[htbp]
  \centering
  \photo[width=0.45\linewidth]{sample-chamber.png}{%
  Top view of the sample chamber, with the removed metal cup cover on
  the left. Four metal pins at the back provide the connection for the
  PCB. The white cable below connects to the PID temperature
  controller.}
  \caption{The sample chamber with its metal cup cover removed, showing
    the pins for connecting the PCB and the cable to the PID temperature
    controller.}
  \label{fig:chamber}
\end{figure}

In normal use, the sample chamber is covered by an aluminum cup (see the upper
left corner of the photograph). The whole assembly is covered by a
stainless steel cover (the dewar) for thermal insulation. If you wish to cool
the sample faster, remove the dewar. You may also remove the aluminum cup, but
in that case stop taking data, since the temperature readout will not be
reliable.

\subsection{Samples and sample preparation}

Samples of \VOtwo\ in a form of thin films (about \SI{100}{\nano\metre} thick)
have been deposited on Si/SiO\textsubscript{2} substrates in another lab on campus.
Contacts to them will be attached by staff members. These samples are rather
fragile, especially those contacts, and should be handled with great care. Ask a
staff member to plug the sample into the holder, at least initially.

The \BTO\ sample is from a commercial distributor. It comes in ceramic form with
many different, randomly oriented microcrystals. Feel free to split off your
sample from larger chunks of the ceramic blocks. Pick a flat and thin piece of
ceramic \BTO, and shape it to a thin plate by lightly sanding on the sides. Keep
in mind that capacitance $C = \varepsilon A/d$: the thinner the better, and the
larger the area the better. Also remember that you will need to estimate $A$ and
$d$ numerically, and so the more regular the sample shape, the easier and more
accurate this estimate will be.

\begin{figure}[htbp]
  \centering
  \photo[width=0.62\linewidth]{silver-paint.png}{%
    Photograph of the sample-preparation bench. On the left stands an open glass
    vial of grey silver paint; behind it is the paint container labeled High
    Purity Silver Paint. In the center of the bench lie a small black two-pin
    connector and a small pale chip of ceramic barium titanate. On the right is
    the vial cap with a long thin wire used to apply the paint.}
  \caption{Materials for mounting the \BTO\ sample: silver paint, a two-pin
           connector, a ceramic chip, and the thin wire used to apply the
           paint.}
  \label{fig:silverpaint}
\end{figure}

The procedure for preparing and mounting the \BTO\ sample is as follows.
\begin{enumerate}
    \item Sand the \BTO\ sample to a uniform size and measure its dimensions.
    \item Apply silver paint to its two broad faces to form the capacitor plates,
        then sand the unpainted sides so that the two plates do not touch.
    \item Check for a short circuit with an ohmmeter.
    \item Apply a thin layer of silver paste to the PCB pad connected to one terminal of the through-hole
        connector, and place one painted face of the sample onto the paste.
    \item Solder a wire to the pad connected to the other terminal and connect
        the wire to the painted upper face of the sample. The two painted faces
        are thus connected to separate PCB pads and separate connector terminals.
    \item Check for a short circuit again through the two connector terminals.
        Be careful not to let the silver paint or paste bridge the two faces:
        you are making a capacitor.
    \item Install the sample in the chamber, the entire PCB is secured in place by the metal clip.
        The two black two-pin connectors on the PCB plug into the first two connector pins in the sample chamber, providing
        the electrical connections to the two painted faces of the sample. You may have to check which lead goes where with a voltmeter.
\end{enumerate}

\notebox{The paint dries very quickly}{Do not leave the silver-paint container
open for an extended period of time; open it for as short an interval as
possible, just long enough to take the paint you need.}

\begin{figure}[htbp]
  \centering
  \photo[width=0.48\linewidth]{sample.png}{%
    Photograph of two green sample-mounting PCBs. The PCB on the left is
    unloaded, showing its contact pads and through-holes. The PCB on the right
    has a \BTO\ sample mounted near the center and two black two-pin connectors.
    One painted face of the sample is attached to a PCB pad with silver paste,
    while a fine wire connects the other painted face to the second contact.
    The two connectors plug onto the four pins in the sample chamber.}
  \caption{An unloaded sample-mounting PCB (left) and a PCB with a mounted
    \BTO\ sample and two two-pin connectors (right).}
  \label{fig:sample}
\end{figure}

A stereo microscope is provided for mounting the sample, although with good eyes
and eye--hand coordination it can be done without the microscope.

\notebox{Return your sample}{The sample of \BTO\ (but not of \VOtwo) you make
for the studies should be returned with your final lab report. Simply attach the
sample with Scotch tape to the first page of your report.}

\begin{figure}[htbp]
  \centering
  \photo[angle=-90, width=0.6\linewidth]{bnc-connections.png}{%
    Photograph of the wiring beside the cylindrical sample chamber.
    Four BNC bulkhead connectors are mounted on a metal panel, with
    colored wires running between the panel and the chamber. Red and
    black lead adapters are attached to the BNC connectors.}
  \caption{Wiring between the sample chamber and the four-connector
    BNC panel.}
  \label{fig:bnc}
\end{figure}

Connect the experimental apparatus: one BNC cable from the signal source to
input~A of the lock-in, and another cable from the lock-in to the BNC leading to
the sample. Check that there is no sample in the sample chamber. (For later use,
when you put in the sample, you need to terminate the other BNC with a short
circuit to ground.)

The Y reading (the out-of-phase component) that you see now is due to
all of the capacitances leading to the sample, including the capacitance
between the Teflon-insulated black wire and ground. Fine-tune the phase
so that this background Y reading is as close to zero as possible.
Keep the sensitivity at \SI{1}{\volt} and insert the sample. The
additional Y signal is due primarily to the sample; use its measured
voltage $V_{\mathrm{meas}}$ in
$C = (V_{\mathrm{meas}}/V_0)/(\omega R_0)$ to calculate the sample's
capacitance. If Y is too small to read clearly, expand the Y display as
described in Section~\ref{sec:lockinsettings}, and turn the expand off
again before recording.

For all of this to work, $V_{\mathrm{meas}}/V_0 = \omega R_0 C$ should be
much less than~1. In Appendix~\ref{app:ac} we derived the exact formula
for calculating the capacitance, and noted that the difference between
the exact and approximate formulae is about \SI{1}{\percent} when
$\delta = 0.1$. Therefore, for an initial oscillator setting of
$V_0 = \SI{0.500}{\volt}$, the systematic error caused by using the
approximate formula is about \SI{1}{\percent} or less if
$V_{\mathrm{meas}}$ is smaller than \SI{50}{\milli\volt}. If the measured
oscillator voltage differs from this setting, use the measured value of
$V_0$ and adjust the voltage limit accordingly. Here
$R_0 = \SI{50}{\ohm}$ and, at \SI{25}{\kilo\hertz},
$\omega = 2\pi f \simeq \SI{1.57e5}{\per\second}$.
If you made a very thin sample and its capacitance is large, you may
go outside this limit. In that case, use the exact formula or reduce
the frequency to \SI{10}{\kilo\hertz} or \SI{5}{\kilo\hertz} and repeat
the phase tuning. If you change the frequency, use its new value of
$\omega$ when calculating the capacitance.

At this point you are ready to measure the temperature dependence of the
capacitance. Keep in mind that we expect the capacitance to increase as we warm
the sample, and select a range where the current signal is less than one third of
the full range. This way you do not have to change sensitivity when the most
interesting part of the measurement is happening.

\subsection{Temperature control}

The front panel of the Omega CN08D3-SR-2U-CM-AC temperature
controller~\cite{ref:pid} is shown in Figure~\ref{fig:tcguts}.
The controller is connected to a nearby solid-state relay. Its
low-power control output turns the relay on and off; the relay, in
turn, switches the separate power circuit that drives the heater
wrapped around the sample chamber (see the photograph of the sample
chamber above). In PID operation, changing the fraction of time that
the relay is on adjusts the average power delivered to the heater.
The input for the temperature controller is a thermocouple
that is placed in the aluminum block of the sample chamber. A
thermocouple is a pair of wires made of two different metals, joined
at one end. When the joined end is at a different temperature from
the free ends, a small voltage appears between the free ends (the
Seebeck effect), typically tens of microvolts per degree Celsius.

\begin{figure}[htbp]
  \centering
  \photo[width=0.50\linewidth]{temperature-controller.png}{%
    Close-up photograph of the front panel of the OMEGA
    CN08D3-SR-2U-CM-AC temperature controller. The upper orange display
    shows a measured temperature of \SI{37.5}{\degreeCelsius}, while the
    lower green display shows a setpoint of \SI{60.0}{\degreeCelsius}.
    The OUT1 indication and output bar are visible below the displays.
    The front panel has F1 and F2 keys, a gear-symbol key, a return-arrow
    key, and down and up arrow keys.}
  \caption{Front panel of the OMEGA CN08D3-SR-2U-CM-AC temperature
    controller, showing the measured temperature and setpoint.}
  \label{fig:tcguts}
\end{figure}

The simplest form of temperature control is ``on/off'' control. You
specify a \emph{setpoint}, the highest temperature needed for the
measurement. When the measured temperature is below it, the
controller turns the heater fully on; when the setpoint is reached,
it turns the heater off. Heat remaining in the chamber may continue
to raise its temperature after the heater turns off. This is called
``overshoot''. As the temperature falls below the setpoint, heating
starts again. Because different parts of the chamber take time to
warm and cool, the temperature may continue to fall before rising
again and may oscillate around the setpoint. ``PID'' control adjusts
the heating output to reduce these oscillations; see
Ref.~\cite{ref:pid} for an introduction to PID control. Compare
the temperature response under on/off and PID control.

For a phase-transition measurement, the heating rate also matters.
In the CN08D3's Slope SV (\texttt{SLOP}) mode, you specify a target
temperature and a rate at which the setpoint rises toward it. PID
control adjusts the heater output, reducing it when necessary to
limit the rate of heating. This helps the sample temperature follow
the measured chamber temperature and is important for obtaining
reliable data. Try different heating rates, examine the data, and
choose a suitable rate based on their quality. The
CN08D3 also has a Program SV (\texttt{PROG}) mode for scheduling
multiple heating and holding steps, but it is optional for this
experiment.

\notebox{Question}{Be ready to answer this question: what is the role of the
``I'' in PID?}

\paragraph{Front-panel operation.}
The controller is operated using the gear-symbol key, the curved-arrow
key, and the down and up arrow keys. From the normal PV/SV display, a
brief press of the gear-symbol key enters Regulation Mode; holding it
for more than three seconds enters Initial Setting Mode. The curved-arrow
key moves through the menu items, and the arrow keys change a value or
option. Press the gear-symbol key to save a setting. The \texttt{F1}
and \texttt{F2} keys have user-defined functions and are not needed here.
On the normal display, PV is the measured temperature and SV is the
setpoint.

To set the temperature unit to Celsius, hold the gear-symbol key for
more than three seconds to enter Initial Setting Mode. Use the
curved-arrow key to find \texttt{tPUN}, then use the up or down arrow
to select \si{\degreeCelsius}. Press the gear-symbol key to save the
setting and return to the normal display. Confirm that the display
shows \si{\degreeCelsius}, and check that SV is set to the desired
temperature.

To select slope heating, hold the gear-symbol key for more than three
seconds to enter Initial Setting Mode. Press the curved-arrow key until
\texttt{CRTS} appears, use the up or down arrow to change \texttt{CONS}
to \texttt{SLOP}, and press the gear-symbol key to save and return to the
normal display. The slope-rate unit is set separately in Initial Setting
Mode using \texttt{EVEC}: its third digit from the left is \(0\) for
\si{\degreeCelsius\per\minute} or \(1\) for
\si{\degreeCelsius\per\second}. Change only this digit if the rate unit
needs to be changed. To set the heating rate, briefly press the
gear-symbol key to enter Regulation Mode, use the curved-arrow key to
find \texttt{SVSL}, set the desired rate with the up or down arrow, and
press the gear-symbol key to save, as shown in Figure~\ref{fig:pid-slope}.

\begin{figure}[htbp]
  \centering
  \photo[angle=-90, width=0.48\linewidth]{temperature-controller-slop.png}{%
    Close-up photograph of the front panel of the
    CN08D3 temperature controller. The display shows the
    \texttt{SVSL} setting for the setpoint slope, with the current value
    shown in green. The gear-symbol, curved-arrow, down-arrow, and
    up-arrow keys are visible below the display.}
  \caption{The OMEGA CN08D3-SR-2U-CM-AC front-panel display for setting
    the SV slope (heating rate).}
  \label{fig:pid-slope}
\end{figure}

To begin heating, press the curved-arrow key from the normal display
until \texttt{R-S} appears. Select \texttt{RUN} with the arrow keys and
press the gear-symbol key to save. Monitor PV and the measurement data
during heating. When the target temperature is reached and cooling data
collection is to begin, use the curved-arrow key to find \texttt{R-S}
again, select \texttt{STOP}, and press the gear-symbol key to save.
Confirm that the heating output is off, then continue recording as the
sample cools. In \texttt{SLOP} mode, reaching the target temperature
does not automatically stop the controller.

\notebox{Hot surfaces and overheating}{Most of the capacitance measurements are
made at temperatures over \SI{100}{\degreeCelsius}. Be careful: the sample
chamber will be hot. Do not exceed \SI{160}{\degreeCelsius}, because the
sample chamber may be damaged. The sample chamber can be seriously overheated
if left unattended with the heater on. Always switch off the temperature
controller when the measurement is done. When using \texttt{SLOP} mode,
reaching the target temperature does not turn off the heater. Set
\texttt{R-S} to \texttt{STOP} and confirm that the heating output is off
before recording the cooling data.}

\subsection{Temperature measurement}

The temperature is measured by a thermocouple installed in the aluminum
block of the sample chamber and connected to the temperature input of
the Omega CN08D3 controller. A thermocouple detects temperature through
the small voltage between its two wires, which grows with the
temperature difference between the junction in the block and the
controller's terminals.

The CN08D3 measures the thermocouple voltage, corrects for the
temperature of its own terminals, and converts the result to the process
temperature (PV). Its input-type setting must match the thermocouple
type. PyFERRO reads the PV
and setpoint (SV) from the controller over RS-485 and records them with
the lock-in measurements. The controller uses the PV as feedback to
regulate the heater. Because the probe measures the aluminum block, its
reading may differ slightly from the temperature at the sample.

The PyFERRO data file contains (1) the time dependence of the
temperature and (2) the temperature dependence of the lock-in output
signals \(X\) and \(Y\). Copy the data file to a thumb drive for
analysis.

Before measuring the sample, use PyFERRO to study the temperature
control process. On the Instruments tab, turn off Simulation mode and
check the connections to the lock-in amplifier and the Omega CN08D3
temperature controller. On the Run tab, select the CN08D3 controller as
the temperature source. Start at room temperature or below
\SI{50}{\degreeCelsius}. On the CN08D3, select constant setpoint mode
(\texttt{CONS}) and set the setpoint to \SI{70}{\degreeCelsius}. Set
the controller's \texttt{CONTROL} mode to \texttt{ON-OFF}. Start
monitoring and recording in PyFERRO, then set the controller to
\texttt{RUN}. Continue recording as the temperature rises and
oscillations develop. Then change the CN08D3's \texttt{CONTROL} mode
from \texttt{ON-OFF} to \texttt{PID} without stopping the recording.
Compare the temperature-versus-time data for the two modes and discuss
your observations in your lab report.

% =============================================================================
\section{Suggested protocol for a measurement}
% =============================================================================

\begin{enumerate}
  \item Tune the lock-in amplifier and place the \VOtwo\ or \BTO\ sample
        in the sample chamber. Close the chamber with its fitted cover. If
        additional thermal insulation is needed, place the larger stainless-steel
        dewar over the covered chamber.
  \item Start the PyFERRO routine (see Appendix~\ref{app:pyferro}).
  \item Set the temperature-controller setpoint on the front panel to
  \SI{90.0}{\degreeCelsius} for a \VOtwo\ measurement or
  \SI{150.0}{\degreeCelsius} for the capacitance measurement of \BTO.
  \item Program the ramp rate. Change the ramp rate and examine the data: you
        want to make sure that your ramp rate is slow enough for the data to be
        reliable. Discuss with the laboratory staff what this means.
  \item Set \texttt{R-S} to \texttt{RUN} to begin heating, the green light on the Solid-State Relay should blink.
  \item Watch the signal as the sample crosses the phase transition. In \VOtwo\
        this will take place over a fairly wide temperature range; in \BTO, in
        a narrow temperature range.
  \item Once the setpoint set \texttt{R-S} to \texttt{STOP} on the temperature controller and
        confirm that the heating output is off. You will take more data while the sample is
        cooling.
  \item The sample will slowly cool while the data is recorded. In the \BTO\
        measurement, nothing interesting happens below \SI{80}{\degreeCelsius},
        so when the temperature reaches \SI{80}{\degreeCelsius} you can take off
        the dewar to speed up the cooling. When measuring a \VOtwo\ sample, you
        want to take the data in a slow-enough ramp mode in the whole
        temperature range.
\end{enumerate}

% =============================================================================
\section{Advice for evaluating the capacitance data}\label{sec:advice}
% =============================================================================

From the graph of the measured capacitance as a function of temperature you will
find the $T_C$ for this material.

Estimate the area of the capacitor and the distance between the plates and
calculate the relative dielectric constant $k$ at room temperature. To find $k$,
you will need to calculate the capacitance $C_0$ of an empty (i.e.\ filled with
vacuum or air) capacitor with the same geometry as your sample, and then take
your measured $C$ and divide it by that calculated $C_0$: $k = C/C_0$.

Give an estimate of the error in $k$ due to the necessarily inaccurate
measurement of the area and the distance between the painted plates. This error
is expected to be large. Compare the value of $k$ to the known dielectric
constant of this ceramic material.

Our main interest, however, is to use the data from our ceramic sample to access
some of the intrinsic, fundamental properties of \BTO. This means that your
values of $k$ will need an important correction, which we discuss here. If the
dielectric constant is very large, the capacitance of the sample should be very
large too. However, in this measurement, the capacitance will not increase near
the transition that much. A possible explanation is that in a ceramic sample the
dielectric polarization is interrupted at the grain boundaries. The capacitance
between the grains provides coupling, but that inter-grain capacitance does not
change with temperature, and certainly does not diverge at $T_C$.

You can model this behavior by taking the sample as \emph{two capacitors in
series}: $C_b$ (capacitance of the grain boundaries) and $C_{BTO}$ (capacitance
of the bulk grains of \BTO). For the effective (measured) capacitance
in this case we have
\begin{equation}
  C = \left[C_b^{-1} + C_{BTO}^{-1}\right]^{-1}.
\end{equation}
Here $C_b$ is independent of the temperature and $C_{BTO}$ corresponds to an
ideal \BTO\ uniformly-filled capacitor. In this model you can assume that at the phase transition
point, when $C_{BTO}$ is very large, the $C_{BTO}^{-1}$ term can be neglected,
and all you measure is $C_b$, i.e.\ $C \approx C_b$. Thus, from your measurement
of the peak capacitance at $T_C$, you will know $C_b$. For all the other
temperatures you can calculate $C_{BTO}$ as
\begin{equation}\label{eq:CBTO}
  C_{BTO} = \frac{C_b\,C}{C_b - C} = \frac{C}{1 - C/C_b},
\end{equation}
where $C$ is the measured capacitance and $C_b$ is the maximum (peak)
capacitance at $T_C$. Therefore, you should use this corrected $C_{BTO}$ and not
the measured capacitance $C$ directly in finding $k$ values: $k = C_{BTO}/C_0$.

Once you obtain corrected $k$ versus $T$ data, refer to
Appendix~\ref{app:physics} (which you should be reading continually while doing
this experiment; it contains most of the physics), analyze Curie--Weiss
dependence of $k$ in the vicinity of the transition, and find Curie--Weiss
constant $C_{CW}$. From it, calculate the microscopic dipole moment and the
displacement of Ti ion in the unit cell based on your data. Compare it to the
displacement you will find in the literature (you will have to find this
value, which is known from X-ray measurements of \BTO). Also calculate the same
quantities using the intrinsic (single-crystalline) value of $C_{CW}$ from the
literature.

\clearpage
\appendix
% =============================================================================
\section{Elements of AC circuit theory relevant to our measurements using the
         lock-in amplifier}\label{app:ac}
% =============================================================================

We are dealing with sinusoidal AC voltages and currents, such as
$V = V_0\cos(\omega t + \gamma)$, where $V_0$ is the amplitude, $\omega$ is the
angular frequency, and $V(t=0) = V_0\cos\gamma$ is the initial condition, i.e.\
a signal at $t = 0$; $\gamma$ is called the \emph{phase angle}, or the
\emph{phase}. You will recall that on a \emph{phasor diagram} which you studied
in your first physics course, all signal amplitudes are represented as rotating
vectors; $\omega$ is the angular velocity of a rotating phasor related to
regular frequency by $\omega = 2\pi f$; projections of these vectors onto a
chosen axis are real instantaneous signals. A \emph{cosine} function used above
corresponds to a projection onto a horizontal axis; if we used a \emph{sine}
function, it would represent a projection onto a vertical axis. In
Figure~\ref{fig:phasorrot} we show $V_0$ at the moment of time $t$, when it makes
an angle $\omega t + \gamma$ with the horizontal; we see $V_0$'s projection onto
the horizontal direction, $V_0\cos(\omega t + \gamma)$, which is the real signal
at the moment $t$.

\begin{figure}[htbp]
  \centering
  \tikzfig[width=0.85\linewidth]{fig-phasor-rotating}{%
    Phasor diagram. A dashed circle is centered on the origin of a pair of faint
    axes. A heavy arrow labeled V-zero runs from the origin to the circle at an
    angle above the horizontal; the angle between the arrow and the positive
    horizontal axis is marked omega t plus gamma. A dashed vertical line drops
    from the tip of the arrow onto the horizontal axis, and the segment of the
    horizontal axis from the origin to that foot is drawn heavy; a callout
    identifies it as V equals V-zero cosine of omega t plus gamma, the projection
    of V-zero onto the horizontal direction, that is, the real signal at the
    moment t. A curved arrow above the circle indicates counterclockwise rotation
    with omega.}
  \caption{A rotating phasor and its projection onto the horizontal axis.}
  \label{fig:phasorrot}
\end{figure}

We will recognize that a phase angle also specifies a \emph{direction} on a
phasor diagram; there is an infinite number of possible radial directions in a
circle.

It is convenient to measure all phases with respect to the phase of the source,
$V_0$. A zero phase angle then corresponds to the direction of $V_0$; we will
call it in what follows the \emph{in-phase} direction. A direction perpendicular
to the in-phase is called \emph{out-of-phase}. It is clear that projections of
$V_0$ onto the in-phase and out-of-phase directions are $V_0$ and zero
respectively.

\begin{figure}[htbp]
  \centering
  \tikzfig[width=0.85\linewidth]{fig-phasor-directions}{%
    Phasor diagram. A dashed circle is crossed by two perpendicular grey lines
    that are tilted with respect to the page: one is labeled in-phase direction
    number one, running from lower left to upper right, and the other is labeled
    out-of-phase direction number two. A heavy arrow labeled V-zero runs from
    the center along the in-phase direction to the circle. A curved arrow above
    the circle indicates counterclockwise rotation with omega.}
  \caption{The in-phase and out-of-phase reference directions, defined relative
           to the source voltage $V_0$.}
  \label{fig:phasordir}
\end{figure}

Deciding to use these two phases (or these two phase directions), we are
effectively setting our initial $\gamma$ to zero. But we will be eventually
measuring average rms values which do not depend on the initial phase; at the
same time, all \emph{relative} phases will be preserved in this new system of
phase referencing.

Measuring a specified phase of a signal (or ``looking'' at a phase, as we say in
electronics) is equivalent to looking at a signal projection onto a chosen
direction in a phasor diagram. While we chose two such directions, in-phase and
out-of-phase with respect to the source voltage $V_0$, the lock-in is capable of
looking at any phase direction. This is one of its advantages over a normal
voltmeter.

With this, let us now consider a phasor of an RC circuit.
Figure~\ref{fig:rcphasor} shows a phasor of a series connection of $R$ and $C$,
with AC source supplying voltage $V_0$; it is a vector sum of voltages $V_R$ and
$V_C$. For completeness we also show the current $I$, which is established in the
circuit; it is shown pointing in the direction of $V_R$. The current is shown
only once because it is the same for all elements in a series connection.

Note that current is said to be \emph{in-phase with the voltage across the
resistor}, $V_R$. We should be careful not to mix our in-phase direction along
$V_0$ as it was defined above with the in-phase direction for the current; these
are two different phase directions, as can be seen on the diagram.

\begin{figure}[htbp]
  \centering
  \tikzfig[width=0.95\linewidth]{fig-rc-phasor}{%
    On the left, a series RC circuit: an AC source supplying V-zero and current I
    drives a resistor R and a capacitor C connected in series. On the right, a
    phasor diagram whose in-phase and out-of-phase reference axes are drawn
    tilted. Three heavy arrows leave the common origin: V-R points up and to the
    right, V-C points down and to the right at right angles to it, and V-zero
    lies between them, completing the rectangle drawn with dashed construction
    lines. A longer arrow along the direction of V-R is labeled I.}
  \caption{Series $RC$ circuit and its phasor diagram.}
  \label{fig:rcphasor}
\end{figure}

It is clear that projections of $V_R$ and $V_C$ onto both in-phase and
out-of-phase directions are non-zero, while the algebraic sum of projections of
vectors $V_R$ and $V_C$ onto the in-phase direction is $V_0$ and to the
out-of-phase direction is zero. Projections of $V_R$ and $V_C$ constitute signals
measured with the lock-in amplifier across $R$ or $C$ respectively, either
in-phase or out-of-phase.

Measuring signals in a particular phase as described above is called
``phase-sensitive'' detection. We are not discussing here how it is practically
implemented in the inside electronics of a lock-in amplifier, but only its
meaning in terms of a phasor diagram.

Measuring resistance is discussed in the main text in
Section~\ref{sec:techniques}; we need to watch for the detrimental effect of a
parasitic capacitance, and the practical solution is to measure at low-enough
frequency.

\subsection{Measuring capacitance}

Here is an illustration of the lock-in tuning process in terms of phasor
diagrams.

\paragraph{Initial tuning.}
The source voltage $V_0$ is directly measured, $V = V_0$. The phase is adjusted
so that there is no out-of-phase component (Figure~\ref{fig:tune1}).

\begin{figure}[htbp]
  \centering
  \tikzfig[width=0.62\linewidth]{fig-tune-initial}{%
    Phasor diagram with a horizontal in-phase axis and a vertical out-of-phase
    axis. A single heavy arrow labeled V-zero equals V lies exactly along the
    in-phase axis, so the out-of-phase component is zero.}
  \caption{Initial tuning: the measured voltage lies entirely along the in-phase
           direction.}
  \label{fig:tune1}
\end{figure}

\paragraph{The capacitor is added to the circuit.}
The voltage drop on the resistor $V_1 = V_R$ and the voltage drop on the
capacitor $V_2 = V_C$, via vector addition, add up to the source voltage
$V_0$. There is a \ang{90} phase difference between $V_R$ and $V_C$. The phasor
diagram looks as shown in Figure~\ref{fig:tune2}. The phase angle $\alpha$ is
given by
\begin{equation}
  \tan\alpha = \frac{V_R}{V_C} = \omega R C .
\end{equation}
For $\omega = 2\pi f = 2\pi \times \SI{25}{\kilo\hertz}$,
$R_0 = \SI{50}{\ohm}$ and $C = \SI{100}{\pico\farad}$ we get
$\tan\alpha = \num{0.00079}$. For such small angles (in radians!) we can safely
take $\tan\alpha = \alpha = \omega R C$.

For $V_0 = \SI{0.500}{\volt}$ the measured out-of-phase voltage is
$V_2 = V_C\sin\alpha$. For small $\alpha$, $V_C \approx V_0$ and
$V_2 = -V_0\,\omega R_0 C = \SI{-0.39}{\milli\volt}$.

\begin{figure}[htbp]
  \centering
  \tikzfig[width=0.66\linewidth]{fig-tune-capacitor}{%
    Phasor diagram with horizontal in-phase and vertical out-of-phase axes. A
    heavy arrow labeled V-C equals V points to the right and slightly downward,
    making a small angle alpha below the in-phase axis. Dashed construction lines
    drop from its tip to the two axes, marking a large in-phase component V-one
    on the horizontal axis and a small negative out-of-phase component V-two on
    the vertical axis.}
  \caption{With the capacitor added, the measured voltage acquires a small
           negative out-of-phase component.}
  \label{fig:tune2}
\end{figure}

\paragraph{The parasitic capacitance, retuned.}
Connecting the measurement circuitry is like adding a capacitor to the circuit.
Here $C = C_p$ represents the sum of all parasitic capacitances. Now we tune the
lock-in so that the out-of-phase component is zero again. The angle $\alpha$ is
still small, so $\tan\alpha = \alpha = \omega R_0 C_p$
(Figure~\ref{fig:tune3}).

\begin{figure}[htbp]
  \centering
  \tikzfig[width=0.66\linewidth]{fig-tune-parasitic}{%
    Phasor diagram with horizontal in-phase and vertical out-of-phase axes. After
    retuning, the heavy arrow labeled V-C equals V lies along the in-phase axis.
    A short arrow labeled V-R points straight up along the out-of-phase axis,
    and the arrow labeled V-zero, the vector sum of the two, lies a small angle
    alpha above the in-phase axis.}
  \caption{After retuning, the measured signal is again purely in-phase; the
           source phasor $V_0$ now sits at the small angle $\alpha$.}
  \label{fig:tune3}
\end{figure}

\paragraph{The sample is added.}
Finally we add the sample. The capacitance gets larger: $C' = C_p + C$, where $C$
is the capacitance of the sample. Since the larger capacitance results in smaller
impedance, the current in the circuit increases, and the voltage drop on the
resistor increases. The phasor diagram now looks as in Figure~\ref{fig:tune4},
where $\tan\beta = \omega R_0 C'$.

\begin{figure}[htbp]
  \centering
  \tikzfig[width=0.68\linewidth]{fig-tune-sample}{%
    Phasor diagram with horizontal in-phase and vertical out-of-phase axes. A
    heavy arrow labeled V-C-prime equals V points to the right and slightly
    downward, at a small angle phi below the in-phase axis. A steeper arrow
    labeled V-R points up and slightly to the right, and their vector sum,
    labeled V-zero, lies at the angle beta above the in-phase axis. Dashed
    construction lines complete the parallelogram.}
  \caption{With the sample inserted, the measured out-of-phase signal is
    $V_2 = V_{C'}\sin\varphi$ with $\varphi = \alpha - \beta$.}
  \label{fig:tune4}
\end{figure}

The measured out-of-phase signal is $V_2 = V_{C'}\sin\varphi$, where
$\varphi = \alpha - \beta$. As long as all of these angles are small, we get
$V_2 = V_0\,\omega R_0 C$, where $C$ is the capacitance of the sample. Therefore
\begin{equation}\label{eq:Cdelta}
  C = \frac{\delta}{\omega R_0},
\end{equation}
where $\delta = -V_2/V_0$ ($\delta$ is a positive quantity and, of course, so is
the capacitance). Here $V_2 = V_{\mathrm{meas}}$.

The capacitance of the typical sample is in the \SI{100}{\pico\farad} range. For
\SI{100}{\pico\farad}, at \SI{25}{\kilo\hertz} and $R_0 = \SI{50}{\ohm}$, the
quantity $\omega R_0 C$ is much less than~1. Therefore, in this limit,
\begin{align}
  V_1/V_0 &\sim 1, \\
  V_2/V_0 &\sim -\omega R_0 C, \\
  C       &= -\frac{V_2/V_0}{\omega R_0} = \frac{\delta}{\omega R_0}.
\end{align}

\subsection{Alternative derivation using complex numbers}

The same result can be obtained using complex numbers instead of phasors.
Complex numbers and symbols for treatment of AC circuits were introduced in the
``Primer to Linear Circuits and Transmission Lines'', posted with the Course
Documents on Blackboard. The impedance of the capacitor is $Z = 1/(j\omega C)$.
The current in the RC circuit shown in Figure~\ref{fig:rccomplex} is
$I = V_0/[R + 1/(j\omega C)]$, and the voltage on the capacitor is

\begin{figure}[htbp]
  \centering
  \tikzfig[width=0.42\linewidth]{fig-rc-complex}{%
    A simple series circuit drawn as a rectangle: a resistor R along the top left,
    a capacitor C along the top right, and an AC source symbol supplying V-zero
    along the bottom.}
  \caption{The series $RC$ circuit used in the complex-number derivation.}
  \label{fig:rccomplex}
\end{figure}

\begin{equation}
  V = \frac{V_0\,/\,j\omega C}{R + 1/j\omega C}
    = \frac{V_0}{1 + j\omega RC}
    = \frac{V_0}{1 + (\omega RC)^2}
      - \frac{j\,V_0\,\omega RC}{1 + (\omega RC)^2}.
\end{equation}
The real and imaginary parts are
\begin{equation}
  V_1 = \frac{V_0}{1 + (\omega RC)^2}
  \qquad\text{and}\qquad
  V_2 = -\frac{V_0\,\omega RC}{1 + (\omega RC)^2}.
\end{equation}
With the proper setting of the lock-in amplifier, described in the main text, we
can measure $V_2$. Since we know $V_0$, $\omega$ and $R$, we can calculate the
capacitance of the sample:
\begin{equation}\label{eq:Cexact}
  C = \frac{1}{\omega R}\,\frac{1 - \sqrt{1 - 4\delta^{2}}}{2\delta},
\end{equation}
where $\delta = -V_2/V_0$ (since the measured voltage is negative, $\delta$ is a
positive number).

So, to summarize, when $\omega R_0 C$ is small ($\ll 1$) we can use formula
$C = \delta/(\omega R)$, but for a very large and thin sample, capacitance will
not be small, and one has to use the complete expression \eqref{eq:Cexact}
derived above. A simple calculation shows that the difference between the exact
and the approximate formula is about \SI{1}{\percent} when $\delta = 0.1$ and
about \SI{5}{\percent} when $\delta = 0.2$.

\clearpage
% =============================================================================
\section{The four-probe method: advantages and limitations}\label{app:fourprobe}
% =============================================================================

A simple resistance measurement is performed either by measuring both the current
through the resistor and the voltage across the resistor (an $I$ and $V$
measurement), as in Figure~\ref{fig:a2f1},

\begin{figure}[htbp]
  \centering
  \tikzfig[width=0.6\linewidth]{fig-a2-two-terminal}{%
    Circuit diagram. Current enters from the left through an ammeter, marked A in
    a circle, and passes through the unknown resistor R-x. A voltmeter, marked V
    in a circle, is connected across R-x between two black dots that mark the two
    terminals.}
  \caption{Two-terminal resistance measurement.}
  \label{fig:a2f1}
\end{figure}

or by measuring a current, supplied by a battery, which flows through an
adjustable resistor and the unknown resistor connected in series, with the scale
being set as to read the unknown resistance (an \emph{ohmmeter} measurement,
which we do not show here). Either way, it is a \emph{two-terminal} measurement:
the unknown resistor is connected to the rest of the circuit at two points, or
two terminals, shown in Figure~\ref{fig:a2f1} as black dots. In this measurement
it is implicitly assumed that \emph{contact resistance} and resistance of the
wires is negligible compared to the resistance $R_x$. In many cases, especially
when dealing with commercially-made resistors, this is an excellent
assumption.

There are however many experimental situations in which this measurement is
complicated by the presence of finite, non-negligible \emph{contact resistance},
and sometimes also by the presence of \emph{lead resistance} (resistance of
electrical connections, wires). Consider for example a measurement performed on a
sample shaped as a uniform-width strip (for example, it may be a thin film
sample). When performing a two-terminal measurement, we place two metal contacts
at the ends of a film strip and attach to them current and voltage leads, as
shown in Figure~\ref{fig:a2f2}.

\begin{figure}[htbp]
  \centering
  \tikzfig[width=0.75\linewidth]{fig-a2-strip}{%
    Diagram of a rectangular film strip with one contact, drawn as a black dot,
    at each end. Current enters from the left through an ammeter marked A and
    leaves at the right; short arrows inside the strip show the current flow
    lines, which spread out around each contact. A voltmeter marked V is
    connected between the same two contacts.}
  \caption{Two-terminal measurement on a sample shaped as a strip, with two
           contacts.}
  \label{fig:a2f2}
\end{figure}

There are at least two problems with this arrangement:

\begin{enumerate}
  \item If there is appreciable contact resistance between the film and the
        contacts (black dots), the equivalent electrical circuit describing this
        measurement will look like the one depicted in Figure~\ref{fig:a2f3},
        where the resistors $R_{\mathrm{cont}}$ indicate the presence of said
        contact resistance. If $R_{\mathrm{cont}}$ is not negligibly small
        compared to $R_x$, the voltage drops across them,
        $2 I R_{\mathrm{cont}}$, will be included in the voltmeter measurement.
        Note that here the full sample current $I$ flows through these
        $R_{\mathrm{cont}}$.
  \item Current flow lines in Figure~\ref{fig:a2f3} may be non-uniform around the
        contacts. This makes the length of a sample ill-determined, and thus will
        introduce an error in the calculation of \emph{resistivity}, even if
        contact resistances were negligible.
\end{enumerate}

\begin{figure}[htbp]
  \centering
  \tikzfig[width=0.8\linewidth]{fig-a2-contact-resistance}{%
    Circuit diagram. Current enters from the left through an ammeter marked A and
    passes through three resistors in series: a contact resistance R-cont, the
    sample resistance R-x, and a second contact resistance R-cont. A voltmeter
    marked V is connected across all three, so that both contact resistances lie
    inside the measured section.}
  \caption{Equivalent circuit showing the presence of contact resistance in a
           two-terminal measurement.}
  \label{fig:a2f3}
\end{figure}

We note that the same un-avoidable problems exist in an ohmmeter two-terminal
measurement.

These problems with the two-terminal connection can be overcome by making a
\emph{four-terminal measurement} described below. This measurement is known under
different names such as the \emph{four-probe method}, a \emph{four-terminal
sensing}, a \emph{four-probe geometry}, or as \emph{Kelvin sensing} (the latter
name is rarely used today; it acknowledges that a similar method was first
described by Lord Kelvin a very long time ago). It is universally used in solid
state physics to perform accurate measurements of true material parameters,
primarily of resistivity $\rho$, as well as in other situations when contact
resistance needs to be excluded from the measurement.

The idea is simple: make current and voltage contacts separately. The current is
measured, and so the results will not depend of current contact resistance. The
two inner voltage leads detect \emph{potential difference} between them. The
current practically does not flow into these inner leads, as the voltmeter
resistance is very high. So again, their contact resistances do not enter into
the picture, except for the case when these resistances are becoming very large,
namely, comparable with the input resistance (impedance) of a voltmeter.

\begin{figure}[htbp]
  \centering
  \tikzfig[width=0.85\linewidth]{fig-a2-four-probe}{%
    Diagram of the four-probe geometry. A rectangular, lightly hatched strip
    sample carries four contacts, drawn as large black dots. The current I enters
    from the left and leaves at the right through lead resistances, passing
    through the two outer contacts, which are labeled a and b. Inside the strip,
    five evenly spaced lines run parallel to its length, marked with arrowheads:
    they fan out from contact a, stay uniform and parallel across the middle of
    the sample, and converge again into contact b, so the current density is
    uniform in the region being measured. A dashed arc near each outer contact
    marks where the flow spreads. The two inner contacts are each connected
    straight up to a probe, and a dashed double-headed arrow across the top,
    labeled V, denotes the voltmeter. A dotted double-headed arrow just above the
    strip, between the two voltage leads, marks the distance L. At the right, a
    pair of dotted arrows above and below the strip marks its width w.}
  \caption{The basic four-probe method.}
  \label{fig:a2f4}
\end{figure}

If the current is $I$ and the potential difference between the inner leads is
$V$, then the resistance of the sample which lies between the voltage leads is
simply $R_S = V/I$. Now we can find the resistivity $\rho$ from the formula
\begin{equation}
  \frac{V}{I} = R_S = \frac{\rho L}{w\delta}
  \qquad\text{or}\qquad
  \rho = R_S\,\frac{w\delta}{L},
\end{equation}
where $w$ is the sample width, $\delta$ is its thickness, and $L$ is the distance
between the voltage leads. Here we assume that we know or can measure sample
geometry (uniform width $w$, uniform thickness $\delta$, distance between voltage
leads $L$).

As we said, this method was designed to exclude from the measurement contact and
wire resistances, and it always achieves this goal once we separate the two sets
of contacts. However, the question of \emph{how accurately} one can find the
absolute value of $\rho$ depends somewhat on the placement and shape of the
middle voltage contacts. If we have four contacts which are essentially large
dots placed along the sample (as is shown in the figure above, and is the case in
this lab when we measure \VOtwo), we will not be able to find $\rho$ exactly. The
reason is that our Figure~\ref{fig:a2f4} is somewhat idealized in that current
may not flow along the sample in such a perfect uniform fashion, being somewhat
disrupted by the middle voltage contacts; additionally, we may have a difficulty
measuring $L$ precisely, as it is essentially known to the uncertainty in the
contact dot size. This is illustrated below in Figure~\ref{fig:a2f5}.

\begin{figure}[htbp]
  \centering
  \tikzfig[width=0.8\linewidth]{fig-a2-imperfections}{%
    Diagram of a strip sample carrying four large contact dots, with a current
    lead entering at each end. Two irregular, wavy lines run from the left-hand
    contact to the right-hand one, marked with arrows to show the current
    direction; they pinch together at each of the two inner contacts and bulge
    apart in between, so the current does not flow uniformly along the strip. A
    solid lead drops well below the strip from each of the two inner contacts.
    Above the strip, a dotted double-headed arrow labeled L with a question mark
    spans the gap between the inner contacts; each of those contacts carries a
    pair of dashed extension lines, one at either edge of the dot, showing that
    the separation can only be read to within the size of a contact dot. A dotted
    arrow drops from the middle of that span onto the top of the strip. Below,
    another dotted arrow points up into the strip and is labeled w with a
    question mark, showing that the width is uncertain too.}
  \caption{Imperfections associated with placing contacts on the sample surface.}
  \label{fig:a2f5}
\end{figure}
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

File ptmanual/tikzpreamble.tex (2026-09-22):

% ---------------------------------------------------------------------------
% tikzpreamble.tex -- shared by main.tex and by every standalone in tikz/
% ---------------------------------------------------------------------------
\usepackage{amsmath}
\usepackage{unicode-math}
\setmathfont{Latin Modern Math}
\usepackage{tikz}
\usepackage{circuitikz}
\usetikzlibrary{arrows.meta,calc,positioning,decorations.pathmorphing,decorations.pathreplacing,
                decorations.markings,patterns,angles,quotes,fit,
                shapes.geometric,shapes.misc,backgrounds,intersections}

\ctikzset{bipoles/length=0.85cm}
\ctikzset{resistors/scale=0.85}
\ctikzset{capacitors/scale=0.9}

\tikzset{
  wire/.style      = {line width=0.7pt},
  dashedwire/.style= {line width=0.7pt, densely dashed},
  term/.style      = {circle, draw, line width=0.6pt, fill=white,
                      inner sep=0pt, minimum size=4.5pt},
  node dot/.style  = {circle, fill=black, inner sep=0pt, minimum size=4pt},
  boxlabel/.style  = {font=\sffamily\small},
  annot/.style     = {font=\small, align=left},
  phasor/.style    = {-{Stealth[length=3.2mm,width=2.2mm]}, line width=1.1pt},
  thinphasor/.style= {-{Stealth[length=2.6mm,width=1.8mm]}, line width=0.7pt},
  axis line/.style = {-{Stealth[length=2.6mm,width=1.8mm]}, line width=0.6pt},
  guide/.style     = {densely dashed, line width=0.4pt, gray},
}
\usepackage{siunitx}

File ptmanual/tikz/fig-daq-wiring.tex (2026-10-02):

% !TEX program = lualatex
\documentclass[border=6pt]{standalone}
\input{../tikzpreamble}
\begin{document}
\begin{tikzpicture}[
    every node/.style={font=\small},
    instr/.style   = {draw, line width=0.8pt, align=center,
                      font=\sffamily\small, inner sep=5pt},
    small instr/.style = {draw, line width=0.8pt, align=center,
                      font=\sffamily\footnotesize, inner sep=4pt},
    lead/.style    = {font=\footnotesize, inner sep=2pt},
  ]

  % =======================================================================
  %  Lock-in amplifier and the measuring circuit
  % =======================================================================
  \draw[wire] (0.2,5.4) rectangle (5.4,7.0);
  \node[boxlabel,font=\sffamily\bfseries] at (2.8,6.55) {Lock-in amplifier};
  \node[boxlabel,font=\sffamily\footnotesize] at (2.8,6.15) {SRS SR830};
  \node[boxlabel,font=\footnotesize] at (1.4,5.72) {Measuring in};
  \node[boxlabel,font=\footnotesize] at (4.5,5.72) {Sine out};
  \foreach \x in {1.0,1.8,4.2,4.7} { \node[term] at (\x,5.4) {}; }

  % ---- sample chamber ----------------------------------------------------
  \draw[dashedwire] (0.2,0.2) rectangle (6.4,3.6);
  \node[boxlabel,font=\sffamily\footnotesize,anchor=north west] at (0.2,0.10)
        {Sample chamber (Al block)};

  % heater winding, with both leads taken out at the bottom right
  \draw[wire,decorate,decoration={coil,aspect=0.5,segment length=3.1mm,amplitude=1.9mm}]
        (1.2,3.15) -- (5.2,3.15);
  \node[lead,anchor=north] at (4.35,2.92) {heater};
  \draw[wire] (1.2,3.15) -- (0.75,3.15) -- (0.75,0.67) -- (6.4,0.67);
  \draw[wire] (5.2,3.15) -- (5.6,3.15) -- (5.6,0.43) -- (6.4,0.43);

  % sample capacitor
  \draw[wire] (2.4,2.30) -- (3.4,2.30);
  \draw[wire,fill=black!12] (2.4,2.05) rectangle (3.4,2.25);
  \draw[wire] (2.4,2.00) -- (3.4,2.00);
  \draw[wire] (2.9,2.30) -- (2.9,4.60);
  \draw[wire] (2.9,2.00) -- (2.9,1.15);
  \node[lead,anchor=west] at (3.55,2.15) {sample};

  % thermocouple in the block
  \draw[wire,fill=white] (5.15,1.55) rectangle (5.85,2.05);
  \draw[wire] (5.85,1.80) -- (6.4,1.80);

  % drive branch through R0, the return, and the measuring leads
  \draw[wire] (4.2,5.4) -- (4.2,4.60) to[R=$R_0$] (2.9,4.60);
  \draw[wire] (4.7,5.4) -- (4.7,1.15) -- (2.9,1.15);
  \draw[wire] (1.0,5.4) -- (1.0,2.75) -- (2.9,2.75);
  \draw[wire] (1.8,5.4) -- (1.8,1.15) -- (2.9,1.15);
  \node[node dot,minimum size=3.2pt] at (2.9,2.75) {};
  \node[node dot,minimum size=3.2pt] at (2.9,1.15) {};

  % =======================================================================
  %  Temperature control
  % =======================================================================
  \draw[wire] (8.6,3.3) rectangle (12.4,5.8);
  \node[boxlabel,font=\sffamily\bfseries] at (10.5,5.40) {PID controller};
  \node[boxlabel,font=\sffamily\footnotesize] at (10.5,5.02) {Omega CN08D3};
  \node[boxlabel,font=\footnotesize,align=left,anchor=north west] at (8.78,4.60)
        {probe in: 10/11/12\\
         OUT1: 8/9\\
         RS-485: 13 (D$-$), 14 (D$+$)};

  \node[small instr] (ssr) at (9.6,0.55) {Solid-state relay};

  % thermocouple -> controller input
  \draw[wire] (6.4,1.80) -- (6.9,1.80) -- (6.9,4.30) -- (8.6,4.30);
  \node[lead,anchor=west] at (7.0,2.55) {thermocouple};

  % heater -> relay (straight into the left-hand side of the relay)
  \draw[wire] (6.4,0.67) -- ($(ssr.west)+(0,0.12)$);
  \draw[wire] (6.4,0.43) -- ($(ssr.west)-(0,0.12)$);
  \node[lead,anchor=south] at (7.3,0.78) {heater power};

  % controller OUT1 -> relay control
  \draw[wire] (9.6,3.3) -- (ssr.north);
  \node[lead,anchor=west] at (9.72,2.10) {OUT1};

  % mains into the relay
  \draw[wire] (ssr.east) -- (11.4,0.55);
  \node[lead,anchor=west] at (11.5,0.55) {AC mains};

  % =======================================================================
  %  Computer links
  % =======================================================================
  \node[instr,minimum width=3.2cm,minimum height=1.4cm] (pc) at (14.9,2.10)
        {Lab PC\\ \footnotesize PyFERRO};
  \node[small instr] (dtech) at (14.9,4.60) {Dtech\\USB $\leftrightarrow$ RS-485};
  \node[small instr] (gpib)  at (12.2,6.60) {NI GPIB adapter};

  % RS-485 from the controller, USB to the PC
  \draw[wire] (12.4,4.60) -- (dtech.west);
  \node[lead,anchor=south] at (13.2,4.68) {RS-485};
  \draw[wire] (dtech.south) -- (pc.north);
  \node[lead,anchor=west] at (15.02,3.45) {USB};

  % GPIB from the lock-in
  \draw[wire] (5.4,6.60) -- (gpib.west);
  \node[lead,anchor=south] at (8.3,6.68) {GPIB, address 8};
  \draw[wire] (gpib.east) -- (16.7,6.60) -- (16.7,2.10) -- (pc.east);
  \node[lead,anchor=west] at (16.82,4.35) {USB};

  % what travels over each link
  \node[annot,font=\footnotesize,anchor=north west] at (13.0,1.20)
        {PyFERRO reads $X$, $Y$ from the lock-in\\
         and $T$, setpoint from the controller};
\end{tikzpicture}
\end{document}

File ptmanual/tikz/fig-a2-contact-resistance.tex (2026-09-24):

% !TEX program = lualatex
\documentclass[border=6pt]{standalone}
\input{../tikzpreamble}
\begin{document}
\begin{tikzpicture}
  \draw[wire] (-1.2,0) -- (0,0);
  \draw[-{Stealth[length=2.6mm]},line width=0.7pt] (-1.2,0) -- (-0.6,0);
  \draw[wire] (0,0) to[rmeterwa, t=A] (1.6,0) -- (2.0,0)
              to[R=$R_{\mathrm{cont}}$] (3.7,0)
              to[R=$R_x$] (5.4,0)
              to[R=$R_{\mathrm{cont}}$] (7.1,0) -- (8.3,0);
  \draw[wire] (2.0,0) -- (2.0,1.9) to[rmeterwa, t=V] (7.1,1.9) -- (7.1,0);
\end{tikzpicture}
\end{document}

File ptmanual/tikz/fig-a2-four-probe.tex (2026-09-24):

% !TEX program = lualatex
\documentclass[border=6pt]{standalone}
\input{../tikzpreamble}
\begin{document}
\begin{tikzpicture}[
    every node/.style={font=\small},
    bigdot/.style={circle, fill=black, inner sep=0pt, minimum size=10pt},
    dimline/.style={line width=1.0pt, densely dotted},
  ]

  % ---- sample strip ------------------------------------------------------
  \fill[pattern=horizontal lines, pattern color=black!16] (1.4,-0.5) rectangle (8.4,0.5);
  \draw[wire] (1.4,-0.5) rectangle (8.4,0.5);

  % ---- current leads -----------------------------------------------------
  \draw[wire] (-1.0,0) -- (1.4,0);
  \draw[wire,fill=white] (-0.55,-0.13) rectangle (0.2,0.13);
  \draw[-{Stealth[length=2.6mm,width=2.2mm]},line width=0.8pt] (0.75,0) -- (1.15,0);
  \node[font=\footnotesize,anchor=south] at (1.15,0.06) {$I$};

  \draw[wire] (8.4,0) -- (10.8,0);
  \draw[-{Stealth[length=2.6mm,width=2.2mm]},line width=0.8pt] (8.55,0) -- (8.95,0);
  \draw[wire,fill=white] (9.2,-0.13) rectangle (9.95,0.13);

  % ---- five current-flow lines: uniform in the middle, fanning out
  %      only where they enter and leave the outer contacts ----------------
  \foreach \dy in {0.30,0.15,0,-0.15,-0.30} {
    \draw[line width=0.6pt]
      (1.8,0) .. controls (2.20,{\dy*0.85}) and (2.35,\dy) .. (2.80,\dy)
              -- (7.10,\dy)
              .. controls (7.55,\dy) and (7.70,{\dy*0.85}) .. (8.1,0);
    \draw[-{Stealth[length=2.0mm,width=1.3mm]},line width=0.6pt]
      (4.80,\dy) -- (5.05,\dy);
  }
  % dashed arcs marking where the flow spreads around the current contacts
  \draw[densely dashed,line width=0.6pt]
        (2.30,0.44) .. controls (2.60,0.16) and (2.60,-0.16) .. (2.30,-0.44);
  \draw[densely dashed,line width=0.6pt]
        (7.60,0.44) .. controls (7.30,0.16) and (7.30,-0.16) .. (7.60,-0.44);

  % ---- the four contacts -------------------------------------------------
  \foreach \x in {1.8,3.5,6.3,8.1} { \node[bigdot] at (\x,0) {}; }
  \node[font=\footnotesize,anchor=south] at (1.8,0.16) {$a$};
  \node[font=\footnotesize,anchor=south] at (8.1,0.16) {$b$};

  % ---- voltage leads and the voltmeter -----------------------------------
  \foreach \x in {3.5,6.3} {
    \draw[wire] (\x,0) -- (\x,3.35);
    \draw[wire,fill=white] (\x-0.16,2.00) rectangle (\x+0.16,2.90);
  }
  \draw[densely dashed,line width=0.8pt,
        {Stealth[length=2.8mm]}-{Stealth[length=2.8mm]}] (3.5,3.25) -- (6.3,3.25);
  \node at (4.9,2.45) {$V$};

  % ---- L : distance between the voltage leads ----------------------------
  \draw[dimline,{Stealth[length=2.8mm]}-{Stealth[length=2.8mm]}] (3.5,0.85) -- (6.3,0.85);
  \node[anchor=south] at (4.9,0.95) {$L$};

  % ---- w : sample width --------------------------------------------------
  \draw[dimline,-{Stealth[length=2.6mm]}] (8.3,1.20) -- (8.3,0.52);
  \draw[dimline,-{Stealth[length=2.6mm]}] (8.3,-0.48) -- (8.3,-1.16);
  \node[font=\footnotesize,anchor=west] at (8.42,1.02) {$w$};
\end{tikzpicture}
\end{document}

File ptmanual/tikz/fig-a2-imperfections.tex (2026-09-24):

% !TEX program = lualatex
\documentclass[border=6pt]{standalone}
\input{../tikzpreamble}
\begin{document}
\begin{tikzpicture}[
    every node/.style={font=\small},
    bigdot/.style={circle, fill=black, inner sep=0pt, minimum size=11pt},
    dimline/.style={line width=1.1pt, densely dotted},
  ]

  % ---- sample strip and current leads ------------------------------------
  \draw[wire] (1.4,-0.55) rectangle (8.0,0.55);
  \draw[wire] (0.2,0) -- (1.4,0);
  \draw[wire] (8.0,0) -- (9.2,0);

  % ---- irregular current-flow lines --------------------------------------
  % They pinch at each contact dot and bulge out in between, so the effective
  % path length between the voltage contacts is ill-defined.
  \draw[wire]
      (1.8,0)  .. controls (2.10,0.30) and (2.50,0.31) .. (2.90,0.23)
               .. controls (3.30,0.15) and (3.45,0.10) .. (3.70,0.12)
               .. controls (4.05,0.14) and (4.30,0.27) .. (4.70,0.27)
               .. controls (5.10,0.27) and (5.30,0.14) .. (5.50,0.12)
               .. controls (5.90,0.09) and (6.15,0.29) .. (6.55,0.29)
               .. controls (6.95,0.29) and (7.25,0.16) .. (7.50,0);
  \draw[wire]
      (1.8,0)  .. controls (2.10,-0.31) and (2.50,-0.32) .. (2.90,-0.24)
               .. controls (3.30,-0.16) and (3.45,-0.11) .. (3.70,-0.13)
               .. controls (4.00,-0.15) and (4.30,-0.25) .. (4.70,-0.25)
               .. controls (5.10,-0.25) and (5.30,-0.14) .. (5.50,-0.13)
               .. controls (5.90,-0.12) and (6.20,-0.27) .. (6.60,-0.27)
               .. controls (7.00,-0.27) and (7.28,-0.15) .. (7.50,0);

  \draw[-{Stealth[length=2.8mm,width=2.4mm]},line width=0.9pt]
        (2.40,0.295) -- (2.78,0.272);
  \draw[-{Stealth[length=2.8mm,width=2.4mm]},line width=0.9pt]
        (2.45,-0.305) -- (2.83,-0.282);

  % ---- the four contacts, drawn large: their size is the whole problem ----
  \foreach \x in {1.8,3.7,5.5,7.5} { \node[bigdot] at (\x,0) {}; }

  % ---- voltage leads from the two inner contacts -------------------------
  \draw[wire] (3.7,0) -- (3.7,-1.95);
  \draw[wire] (5.5,0) -- (5.5,-1.95);

  % ---- L?  : a pair of extension lines straddles each contact dot --------
  \foreach \x in {3.49,3.91,5.29,5.71} { \draw[guide,black] (\x,0.42) -- (\x,1.36); }
  \draw[dimline,{Stealth[length=2.8mm]}-{Stealth[length=2.8mm]}] (3.55,1.20) -- (5.65,1.20);
  \node[anchor=south] at (4.6,1.30) {$L$\,?};
  \draw[dimline,-{Stealth[length=2.8mm]}] (4.6,1.18) -- (4.6,0.56);

  % ---- w?  : arrow pointing up into the strip ----------------------------
  \draw[dimline,-{Stealth[length=2.8mm]}] (4.6,-1.55) -- (4.6,-0.30);
  \node[anchor=north] at (4.6,-1.66) {$w$\,?};
\end{tikzpicture}
\end{document}

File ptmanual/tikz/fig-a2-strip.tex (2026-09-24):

% !TEX program = lualatex
\documentclass[border=6pt]{standalone}
\input{../tikzpreamble}
\begin{document}
\begin{tikzpicture}
  % strip sample
  \draw[wire] (1.6,-0.55) rectangle (6.4,0.55);
  \draw[wire] (2.1,0) .. controls (3.2,0.34) and (4.8,0.34) .. (5.9,0);
  \draw[wire] (2.1,0) .. controls (3.2,-0.34) and (4.8,-0.34) .. (5.9,0);
  \foreach \x in {2.7,3.5,4.3} {
    \draw[-{Stealth[length=2.2mm]},line width=0.6pt] (\x,0.16) -- (\x+0.35,0.16);
    \draw[-{Stealth[length=2.2mm]},line width=0.6pt] (\x,0)    -- (\x+0.35,0);
    \draw[-{Stealth[length=2.2mm]},line width=0.6pt] (\x,-0.16)-- (\x+0.35,-0.16);
  }
  \node[node dot] at (2.1,0) {};
  \node[node dot] at (5.9,0) {};

  % current leads
  \draw[wire] (-1.4,0) -- (0,0);
  \draw[-{Stealth[length=2.6mm]},line width=0.7pt] (-1.4,0) -- (-0.9,0);
  \draw[wire] (0,0) to[rmeterwa, t=A] (1.6,0);
  \draw[wire] (6.4,0) -- (7.6,0);
  \draw[-{Stealth[length=2.6mm]},line width=0.7pt] (7.0,0) -- (7.6,0);

  % voltmeter
  \draw[wire] (2.1,0.55) -- (2.1,1.8) to[rmeterwa, t=V] (5.9,1.8) -- (5.9,0.55);
\end{tikzpicture}
\end{document}

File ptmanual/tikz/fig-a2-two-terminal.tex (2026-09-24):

% !TEX program = lualatex
\documentclass[border=6pt]{standalone}
\input{../tikzpreamble}
\begin{document}
\begin{tikzpicture}
  \draw[wire] (-1.2,0) -- (0,0);
  \draw[-{Stealth[length=2.6mm]},line width=0.7pt] (-1.2,0) -- (-0.6,0);
  \draw[wire] (0,0) to[rmeterwa, t=A] (1.6,0) -- (2.2,0)
              to[R=$R_x$] (4.2,0) -- (4.8,0) -- (6.0,0);
  \node[node dot] at (2.2,0) {};
  \node[node dot] at (4.2,0) {};
  \draw[wire] (2.2,0) -- (2.2,1.5) to[rmeterwa, t=V] (4.2,1.5) -- (4.2,0);
\end{tikzpicture}
\end{document}

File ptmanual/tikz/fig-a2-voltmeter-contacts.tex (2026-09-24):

% !TEX program = lualatex
\documentclass[border=6pt]{standalone}
\input{../tikzpreamble}
\begin{document}
\begin{tikzpicture}
  \draw[densely dashed,line width=0.5pt] (1.0,2.55) rectangle (6.6,4.55);
  \node[font=\footnotesize,anchor=south] at (3.8,4.6) {Voltmeter};
  \draw[wire] (1.6,3.55) to[R=$R_{\mathrm{imp}}$] (3.7,3.55)
              to[rmeterwa, t=G] (5.3,3.55) -- (6.2,3.55);
  \draw[wire] (6.2,3.55) -- (6.2,2.1) to[R=$R_{\mathrm{cont}}$] (6.2,0.6) -- (6.2,0);
  \draw[wire] (1.6,3.55) -- (1.6,2.1) to[R,l_=$R_{\mathrm{cont}}$] (1.6,0.6) -- (1.6,0);

  \draw[wire] (-0.6,0) -- (1.6,0) to[R=$R_x$] (4.6,0) -- (6.2,0) -- (7.2,0);
  \node[node dot,minimum size=3.2pt] at (1.6,0) {};
  \node[node dot,minimum size=3.2pt] at (6.2,0) {};

  \draw[-{Stealth[length=2.4mm]},line width=0.7pt] (1.6,2.12) -- (1.6,2.5);
  \node[font=\footnotesize,anchor=east] at (1.5,2.26) {$I_G$};
  \draw[-{Stealth[length=2.4mm]},line width=0.7pt] (0.1,0) -- (0.55,0);
  \node[font=\footnotesize,anchor=south] at (0.1,0.08) {$I$};
  \draw[-{Stealth[length=2.4mm]},line width=0.7pt] (2.0,0) -- (2.45,0);
  \node[font=\footnotesize,anchor=south] at (2.15,0.08) {$I-I_G$};
\end{tikzpicture}
\end{document}

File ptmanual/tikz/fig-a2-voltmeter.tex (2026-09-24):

% !TEX program = lualatex
\documentclass[border=6pt]{standalone}
\input{../tikzpreamble}
\begin{document}
\begin{tikzpicture}
  % voltmeter box
  \draw[densely dashed,line width=0.5pt] (1.0,1.05) rectangle (6.6,3.05);
  \node[font=\footnotesize,anchor=south] at (3.8,3.1) {Voltmeter};
  \draw[wire] (1.6,2.05) to[R=$R_{\mathrm{imp}}$] (3.7,2.05)
              to[rmeterwa, t=G] (5.3,2.05) -- (6.2,2.05) -- (6.2,0);
  \draw[wire] (1.6,2.05) -- (1.6,0);

  % sample branch
  \draw[wire] (-0.6,0) -- (1.6,0) to[R=$R_x$] (4.6,0) -- (6.2,0) -- (7.2,0);
  \node[node dot,minimum size=3.2pt] at (1.6,0) {};
  \node[node dot,minimum size=3.2pt] at (6.2,0) {};

  \draw[-{Stealth[length=2.4mm]},line width=0.7pt] (1.6,0.55) -- (1.6,1.05);
  \node[font=\footnotesize,anchor=east] at (1.5,0.62) {$I_G$};
  \draw[-{Stealth[length=2.4mm]},line width=0.7pt] (0.1,0) -- (0.55,0);
  \node[font=\footnotesize,anchor=south] at (0.1,0.08) {$I$};
  \draw[-{Stealth[length=2.4mm]},line width=0.7pt] (2.0,0) -- (2.45,0);
  \node[font=\footnotesize,anchor=south] at (2.15,0.08) {$I-I_G$};
\end{tikzpicture}
\end{document}

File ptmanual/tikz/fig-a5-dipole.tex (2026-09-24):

% !TEX program = lualatex
\documentclass[border=6pt]{standalone}
\input{../tikzpreamble}
\begin{document}
\begin{tikzpicture}[every node/.style={font=\small}]
  \node[circle,draw,line width=0.7pt,minimum size=8mm] (mq) at (0,0) {$-q$};
  \node[circle,draw,line width=0.7pt,minimum size=8mm] (pq) at (0,-2.6) {$+q$};
  \draw[line width=0.9pt] (mq) -- (pq);
  \draw[{Stealth[length=2.6mm]}-{Stealth[length=2.6mm]},line width=0.6pt]
       (0.85,-0.4) -- (0.85,-2.2);
  \node[anchor=west] at (0.95,-1.3) {$x$};
  \node[anchor=west] at (1.9,-1.3) {$p=qx$};
\end{tikzpicture}
\end{document}

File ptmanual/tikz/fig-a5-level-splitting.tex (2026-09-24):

% !TEX program = lualatex
\documentclass[border=6pt]{standalone}
\input{../tikzpreamble}
\begin{document}
\begin{tikzpicture}[every node/.style={font=\small}]
  \draw[axis line] (0,-1.6) -- (0,1.9);
  \node[anchor=south west,font=\footnotesize] at (-0.1,1.95) {Dipole energy};

  % unsplit level
  \draw[line width=0.9pt] (0.9,0) -- (3.3,0);
  \node[anchor=south,font=\footnotesize] at (2.1,0.08) {$N$ ($E=0$)};

  % splitting
  \draw[line width=0.9pt] (3.3,0) -- (4.4,0.75) -- (7.2,0.75);
  \draw[line width=0.9pt] (3.3,0) -- (4.4,-0.75) -- (7.2,-0.75);
  \node[anchor=south,font=\footnotesize] at (6.1,0.9) {$N/2\,\exp(-\Delta U/2k_BT)$};
  \node[anchor=north,font=\footnotesize] at (6.1,-0.9) {$N/2\,\exp(\Delta U/2k_BT)$};

  % dipole arrows
  \draw[-{Stealth[length=2.2mm]},line width=0.8pt] (4.75,0.42) -- (4.75,0.72);
  \node[anchor=west,font=\footnotesize] at (4.82,0.57) {$p$};
  \draw[-{Stealth[length=2.2mm]},line width=0.8pt] (4.75,-0.42) -- (4.75,-0.72);
  \node[anchor=west,font=\footnotesize] at (4.82,-0.57) {$p$};

  % energy difference
  \draw[{Stealth[length=2.4mm]}-{Stealth[length=2.4mm]},line width=0.6pt]
       (6.9,0.75) -- (6.9,-0.75);
  \node[anchor=west,font=\footnotesize] at (7.3,0) {$\Delta U = 2pE$};

  % field
  \draw[-{Stealth[length=3.2mm]},line width=1.3pt] (9.6,1.5) -- (9.6,-1.2);
  \node[anchor=west,font=\footnotesize] at (9.75,0.2) {$\mathbf{E}$};
\end{tikzpicture}
\end{document}

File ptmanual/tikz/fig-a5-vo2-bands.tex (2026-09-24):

% !TEX program = lualatex
\documentclass[border=6pt]{standalone}
\input{../tikzpreamble}
\begin{document}
\begin{tikzpicture}[every node/.style={font=\small}]
  % ---------------- semiconducting side ----------------------------------
  \draw[wire] (0,1.75) rectangle (4.0,3.4);
  \node at (2.0,2.55) {Conduction Zone};
  \draw[wire,pattern=horizontal lines,pattern color=black!45] (0,0) rectangle (4.0,1.05);
  \draw[wire] (0,0) rectangle (4.0,1.05);
  \node[fill=white,inner sep=2pt] at (2.0,0.5) {Valence Zone};

  % ---------------- metallic side ----------------------------------------
  \draw[wire] (4.3,1.4) rectangle (8.3,3.4);
  \node at (6.3,2.55) {Empty states};
  \draw[wire,pattern=horizontal lines,pattern color=black!45] (4.3,0) rectangle (8.3,1.4);
  \draw[wire] (4.3,0) rectangle (8.3,1.4);
  \node[fill=white,inner sep=2pt] at (6.3,0.7) {Filled states};

  % ---------------- Fermi level & gap ------------------------------------
  \draw[densely dashed,line width=0.8pt] (0,1.4) -- (8.3,1.4);
  \draw[guide,black] (0,1.05) -- (-0.55,1.05);
  \draw[guide,black] (0,1.75) -- (-0.55,1.75);
  \draw[{Stealth[length=2.4mm]}-{Stealth[length=2.4mm]},line width=0.6pt]
        (-0.4,1.05) -- (-0.4,1.75);
  \node[anchor=east,font=\footnotesize] at (-0.5,1.4) {$E_g$};

  \node[anchor=north,font=\footnotesize] at (2.0,-0.15) {Semiconductor at $T<T_C$};
  \node[anchor=north,font=\footnotesize] at (6.3,-0.15) {Metal at $T>T_C$};
\end{tikzpicture}
\end{document}

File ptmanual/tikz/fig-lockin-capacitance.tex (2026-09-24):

% !TEX program = lualatex
\documentclass[border=6pt]{standalone}
\input{../tikzpreamble}
\begin{document}
\begin{tikzpicture}[every node/.style={font=\small}]

  % ---- lock-in box -------------------------------------------------------
  \draw[wire] (0,0) rectangle (9.6,1.9);
  \node[boxlabel,font=\sffamily\bfseries] at (4.8,1.45) {Lock-in amplifier};
  \node[boxlabel] at (2.6,0.6) {Measuring input};
  \node[boxlabel] at (7.8,0.6) {Oscillator voltage out};

  \foreach \x in {1.2,2.9,7.6,8.9} { \node[term] at (\x,0) {}; }
  \node[font=\footnotesize] at (2.05,-0.55) {$V_{\mathrm{meas}}$};
  \node[font=\footnotesize,anchor=east] at (7.45,-0.55) {$V_0$ rms};

  % ---- oscillator branch through R0 -------------------------------------
  \draw[wire] (7.6,-0.09) -- (7.6,-1.1)
              to[R=$R_0$] (7.6,-2.6)
              -- (7.6,-4.0) -- (5.4,-4.0);

  % ---- sample capacitor --------------------------------------------------
  \draw[wire] (5.4,-4.0) -- (5.4,-4.55);
  \draw[wire] (4.85,-4.55) -- (5.95,-4.55);
  \draw[wire,fill=black!12] (4.85,-4.75) rectangle (5.95,-4.95);
  \draw[wire] (4.85,-5.15) -- (5.95,-5.15);
  \draw[wire] (5.4,-5.15) -- (5.4,-5.7);
  \node[node dot,minimum size=3.2pt] at (5.4,-4.0) {};
  \node[node dot,minimum size=3.2pt] at (5.4,-5.7) {};
  \node[font=\footnotesize,anchor=south east] at (5.3,-3.92) {1};
  \node[font=\footnotesize,anchor=south west] at (5.5,-4.5)  {2};
  \node[font=\footnotesize,anchor=north east] at (5.3,-5.78) {3};
  \node[font=\footnotesize,anchor=north west] at (5.5,-5.2)  {4};
  \node[font=\footnotesize,anchor=west] at (6.1,-4.85) {sample};

  % ---- return branch -----------------------------------------------------
  \draw[wire] (8.9,-0.09) -- (8.9,-6.6) -- (5.4,-6.6) -- (5.4,-5.7);

  % ---- measuring leads ---------------------------------------------------
  \draw[wire] (2.9,-0.09) -- (2.9,-4.0) -- (5.4,-4.0);
  \draw[wire] (1.2,-0.09) -- (1.2,-5.7) -- (5.4,-5.7);

  % ---- parasitic capacitance --------------------------------------------
  \draw[dashedwire] (3.8,-4.0) to[C] (3.8,-5.7);
  \node[font=\footnotesize,anchor=east] at (3.65,-4.85) {$C_p$};
\end{tikzpicture}
\end{document}

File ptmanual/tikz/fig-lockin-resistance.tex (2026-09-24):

% !TEX program = lualatex
\documentclass[border=6pt]{standalone}
\input{../tikzpreamble}
\begin{document}
\begin{tikzpicture}[every node/.style={font=\small}]

  % ---- lock-in box -------------------------------------------------------
  \draw[wire] (0,0) rectangle (9.4,1.9);
  \node[boxlabel,font=\sffamily\bfseries] at (4.7,1.45) {Lock-in amplifier};
  \node[boxlabel] at (3.5,0.6) {Measuring input};
  \node[boxlabel] at (7.7,0.6) {Oscillator voltage out};

  % terminals
  \foreach \x in {2.6,4.4,7.0,8.4} { \node[term] at (\x,0) {}; }

  \node[font=\footnotesize] at (3.5,-0.55) {$V_{\mathrm{meas}}$};
  \node[font=\footnotesize,anchor=east] at (6.85,-0.55) {$V_0$ rms};

  % ---- sample ------------------------------------------------------------
  \draw[wire,fill=black!5] (1.0,-5.78) rectangle (6.2,-5.22);
  \foreach \x in {1.4,2.6,4.4,5.8} { \node[node dot] at (\x,-5.5) {}; }
  \node[font=\footnotesize,anchor=north] at (1.4,-5.92) {$I_{+}$};
  \node[font=\footnotesize,anchor=north] at (2.6,-5.92) {$V_{+}$};
  \node[font=\footnotesize,anchor=north] at (4.4,-5.92) {$V_{-}$};
  \node[font=\footnotesize,anchor=north] at (5.8,-5.92) {$I_{-}$};

  % ---- measuring leads ---------------------------------------------------
  \draw[wire] (2.6,-0.09) -- (2.6,-5.5);
  \draw[wire] (4.4,-0.09) -- (4.4,-5.5);

  % ---- parasitic capacitance (in parallel with the inner leads) ----------
  \draw[dashedwire] (2.6,-4.5) to[C] (4.4,-4.5);
  \node[font=\footnotesize] at (3.5,-4.15) {$C_p$};

  % ---- oscillator branch: R0 and RD in series ---------------------------
  \draw[wire] (7.0,-0.09) -- (7.0,-1.0)
              to[R=$R_0$] (7.0,-2.4)
              -- (7.0,-3.2)
              to[vR=$R_D$] (7.0,-4.8)
              -- (7.0,-5.5) -- (5.8,-5.5);

  % ---- return branch -----------------------------------------------------
  \draw[wire] (8.4,-0.09) -- (8.4,-6.75) -- (0.3,-6.75) -- (0.3,-5.5) -- (1.4,-5.5);
\end{tikzpicture}
\end{document}

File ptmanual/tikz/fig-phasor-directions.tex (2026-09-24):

% !TEX program = lualatex
\documentclass[border=6pt]{standalone}
\input{../tikzpreamble}
\begin{document}
\begin{tikzpicture}[every node/.style={font=\small}]
  \def\R{2.3}
  \draw[densely dashed,gray] (0,0) circle (\R);
  % the two reference directions
  \draw[line width=0.5pt,gray] (215:\R) -- (35:\R);
  \draw[line width=0.5pt,gray] (305:\R) -- (125:\R);

  \draw[phasor] (0,0) -- (35:\R) node[anchor=south west,inner sep=2pt] {$V_0$};

  \draw[-{Stealth[length=3mm]},line width=0.7pt]
       (1.95,1.75) arc[start angle=45,end angle=95,radius=2.8];
  \node[annot,anchor=west] at (2.9,1.9)
       {The phasor rotates\\ counterclockwise with $\omega$};

  \draw[-{Stealth[length=2.6mm]},line width=0.5pt] (-3.0,-1.2) -- (215:\R);
  \node[annot,anchor=east] at (-3.05,-1.25) {\textit{In-phase} direction (1)};

  \draw[-{Stealth[length=2.6mm]},line width=0.5pt] (2.3,-2.35) -- (305:\R);
  \node[annot,anchor=west] at (2.35,-2.4) {\textit{Out-of-phase} direction (2)};
\end{tikzpicture}
\end{document}

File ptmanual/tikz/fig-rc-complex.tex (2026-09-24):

% !TEX program = lualatex
\documentclass[border=6pt]{standalone}
\input{../tikzpreamble}
\begin{document}
\begin{tikzpicture}
  \draw[wire] (0,0) to[R=$R$] (2.2,0) to[C=$C$] (4.4,0) -- (4.4,-1.3)
              to[sV=$V_0$] (0,-1.3) -- (0,0);
\end{tikzpicture}
\end{document}

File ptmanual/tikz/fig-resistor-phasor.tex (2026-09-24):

% !TEX program = lualatex
\documentclass[border=6pt]{standalone}
\input{../tikzpreamble}
\begin{document}
\begin{tikzpicture}[every node/.style={font=\small}]

  % ---- circuit -----------------------------------------------------------
  \begin{scope}[shift={(0,0)}]
    \draw[wire] (0,0) to[sV=$V_0$,invert] (0,2.6)
                      to[R=$R_0$] (2.6,2.6)
                      to[R=$R_S$] (2.6,0)
                      to[R=$R_D$] (0,0);
  \end{scope}

  % ---- phasor diagram ----------------------------------------------------
  \begin{scope}[shift={(5.4,1.3)}]
    \draw[axis line] (0,-1.25) -- (0,1.4);
    \draw[axis line] (-0.9,0)  -- (4.6,0);
    \node[anchor=north east,font=\footnotesize] at (-0.12,-0.55) {out-of-phase};
    \node[anchor=north,font=\footnotesize] at (2.1,-0.1) {in-phase};
    \draw[phasor] (0,0) -- (3.5,0);
    \node[anchor=south west] at (0.25,0.5)
      {$V_{R_S}=I R_S = V_0 R_S/(R_S+R_0+R_D)$};
    % rotation arrow
    \draw[-{Stealth[length=3mm]},line width=0.7pt]
      (6.3,1.15) arc[start angle=70,end angle=-70,radius=1.25];
    \node[anchor=west] at (6.8,0) {$\omega$};
  \end{scope}
\end{tikzpicture}
\end{document}

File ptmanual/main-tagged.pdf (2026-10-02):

## Phase Transitions: Metal–Insulator Transition in VO2

## and Ferroelectric Transition in BaTiO3

Advanced Laboratory
Department of Physics & Astronomy Stony Brook University
Write-up version of September 2026
Sections on ferroelectricity in BaTiO3

by Laszlo Mihaly and, in part, Michael Gurvitch; sections on phase-transition theory and the metal–insulator transition in VO2

by Michael Gurvitch.

## Contents

Pre-experiment and mid-experiment evaluation sheet | 4
1 How to prepare for the measurement | 5
2 Goals of the experiment | 5
3 Experimental set-up | 6
4 Principle of the measurement and an overview of data analysis | 6

### 5 Looking ahead: what should and should not be included in your Final Report 8

6 Measurement techniques | 9
7 The rest of the experimental apparatus in detail | 17
8 Suggested protocol for a measurement | 23
9 Advice for evaluating the capacitance data | 23
A Elements of AC circuit theory relevant to our measurements using the lock-in
amplifier | 25
B The four-probe method: advantages and limitations | 30
C Data taking with PyFERRO | 35
D Physics of phase transitions | 38

D.3.1 First-order transitions from the thermodynamic point of view; mixed-phase D.3.2 Second-order transitions from the thermodynamic point of view; elements

D.4.4 MIT in VO2
D.4.5 Development of a mixed state and hysteresis in VO2 D.5 BaTiO3

D.6 Paraelectric to ferroelectric transition; Curie–Weiss law | 54
D.7 Derivation of CCW in terms of a microscopic dipole moment | 55
References | 59

## Pre-experiment and mid-experiment evaluation sheet

You must meet with a staff member for the experiment you are doing before beginning an experiment and before the lab period indicated in the middle of the experiment for an evaluation of your preparation and your progress to date. This form must be signed and dated by the staff member to indicate you have done the required work to date. It must be attached as the first page of your report. You will lose one grade point from your report grade for each section of this form that is not properly signed on time. If this is your first experiment you should also be prepared to demonstrate you have read and understood the information on log books in the course notes.
Student name
Partner name
Pre-lab discussion
Be prepared to demonstrate you have read the background material for this experiment (most of this material is contained in this write-up, but also in cited references; it includes theory described in Appendix A). Discuss the following questions with the staff:
1. Describe what we mean by phase transitions; give some examples; what is the difference between phase transitions of the first and second kind? Experimentally, in this lab, how can we tell which transition it is?
2. Give a general description of a metal–insulator transition; what happens to the electronic spectrum of a solid when this transition takes place? What is the most direct manifestation of this transition, and how can it be detected? Is this transition taking place all at once in the whole sample, or not (explain)?
3. Explain what ferroelectricity is and what the mechanism for it in BaTiO3

is.
4. What does a PID controller do? Be specific about its principle of operation.
5. What is the general principle of operation of a lock-in amplifier?

Completed before first period for the experiment? Yes/ No
Staff comments
Staff signature | Date

## 1 How to prepare for the measurement

This write-up contains a lot of material. You should study parts of it before coming to the lab, and read and study the entire text throughout the course of this experiment.
Note. A big chunk of this manual is in the Appendices, so do not treat them as secondary-importance material.
You should also supplement this write-up by looking up and reading some of the books/arti-cles/websites from the list of references. We propose that you start in the following order: First read Sections 2–5, which will give you an overview of this lab. Then spend some time learning how to use the lock-in amplifier. Your first task will be to master preliminary practice measurements of resistance and capacitance. During the first two periods of the lab work, concentrate on Section 6 of this write-up entitled “Measurement techniques” and study Appendices A and B. Read the equipment manual for the lock-in amplifier and Ref. [2]; study the principle of its operation. Simultaneously, study the instrument hands-on: connect a circuit and first measure a known resistor, and then a known capacitor, using the lock-in.
Once you get familiarized with using the lock-in, read about the rest of the experimental set-up, which is described in Sections 7–9. Then you should start reading more of a physics theory, which is to be found mainly in a large Appendix D. The physics of phase transitions is not trivial, and it will take time to “digest” and understand it.
From the beginning, keep good records in your notebook. All electrical circuits that you will build, simple calculations which accompany construction of these circuits, such as estimates of the measuring current, choice of a limiting resistor, calculations of resistance and capacitance, sketches of samples or experimental apparatus, details of sample preparation and geometry, all notes concerning physics, and all your calculations of physical quantities should be recorded in the notebook. Short comments you may write should be understandable, in case you or someone else will later examine your records. The actual experimental data will be stored in the computer and need not be in the notebook.

## 2 Goals of the experiment

- Understand experimental techniques used in this lab, including the principle and practical operation of a lock-in amplifier when measuring resistance and capacitance, the four-probe method, temperature control.
- Learn to handle and prepare samples; learn how to quickly check samples before they are used in lengthy measurements.
- Study the metal–insulator transition in VO2
- Study the ferroelectric transition in BaTiO3
- Learn basic physics associated with phase transitions and apply it to interpreting specific experiments at hand.
- We do not just do measurements for the sake of measurements. An experiment should lead to some conclusions and it should culminate and result in learning of some “new” physics (new to us in this lab; perhaps not new to the physics community). Therefore it is very important to use your data to extract some meaningful physical results: namely, estimates of microscopic or theoretical quantities which enhance our quantitative understanding of the studied phenomena. You will do so for both phase transitions studied in this lab.

## 3 Experimental set-up

- Sample chamber with four electric leads.
- Temperature controller.
- Lock-in amplifier (SRS SR830) to measure the samples.
- HP 34401A multimeter (not needed for the standard measurement).
- Computer (username LabStudent, password PhaseTransition).
- Decade resistance box, additional resistors, capacitors, BNC cables etc.
The Omega CN08D3-SR-2U-CM-AC temperature controller controls the heater and can be programmed from its front panel, connected to the computer via RS-485. The lock-in amplifier is connected to the computer by the IEEE 488 (GPIB) interface and PyFERRO displays and records all measurements in real time.

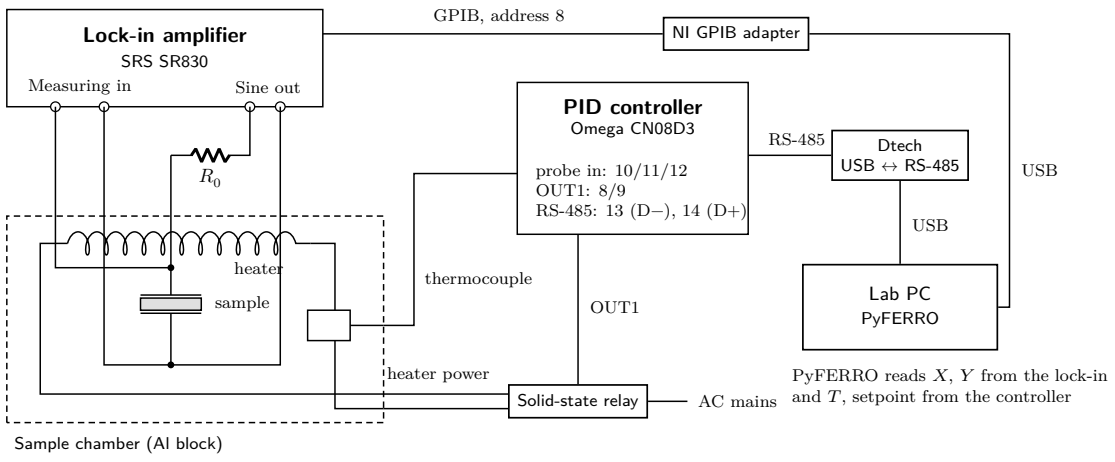
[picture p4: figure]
Lock-in amplifier SRS SR830; Measuring in; Sine out; Sample chamber (Al block); heater sample; PID controller Omega CN08D3; probe in: 10/11/12 OUT1: 8/9 RS-485: 13 (D−), 14 (D+); Solid-state relay; thermocouple; heater power; OUT1; AC mains; Lab PC PyFERRO; Dtech USB ↔ RS-485; NI GPIB adapter; USB; GPIB, address 8; PyFERRO reads X, Y from the lock-in and T, setpoint from the controller

Figure 1: Instrument connections for the temperature-dependent measurement.

## 4 Principle of the measurement and an overview of data analysis

Details on these subjects will be found in the rest of this write-up; and you know what they say: the devil is in the details. Here is the brief summary:
You will be studying two different phase transitions, both taking place as a function of temperature: a metal–insulator transition in vanadium dioxide (VO2

) and a ferroelectric transition in barium titanate (BaTiO3

). Read Appendix D where the physics of phase transitions is reviewed and detailed.
The sample is placed in a temperature-controlled chamber. The temperature is slowly changed, first rising, and then cooling down, while either resistance R (in VO2

) or capacitance C (with
BaTiO3

serving as dielectric) is measured and data is recorded. The temperature will change between room temperature and about 100 °C in the case of VO2

, and between room temperature and about 150 °C in the case of BaTiO3

. The measurement of R and C is performed in an AC mode using a lock-in amplifier, which is described below in Section 6 and in Appendix A. What will you be able to learn from these measurements? In the case of the resistive VO2 data, you will be able to make conclusions concerning the nature and order of a phase transition, including estimates of the metal–insulator transition temperature, of the percolation transition temperature, of the coercive temperature. You will also be able to analyze the data to extract the gap of VO2

in a semiconducting phase and to estimate absolute resistivities of the two phases. In the case of a capacitance measurement, BaTiO3 will be the dielectric inside a capacitor. In a parallel-plate capacitor,
C = εA
d

=

ε0kA
d
, | (1)
where A is the area of the capacitor, d is the distance between the plates, ε is the dielectric constant, ε0

is a constant called the permittivity of free space, and k is the relative dielectric constant. We will be interested in finding k as a function of temperature. It will not be possible to exactly measure A and d in the type of samples you will have, but they can be roughly estimated. So, by measuring C (which is measured quite precisely), you will be able to estimate k to within about a factor of two accuracy, the uncertainty coming almost entirely from a limited ability here to evaluate capacitor geometry. At the same time, you can certainly follow how k will change with temperature with the full precision of the capacitance measurement. This T -dependence will pinpoint the temperature of a phase transition, TC. Combined, these data will allow a calculation of microscopic parameters of a ferroelectric transition as outlined in Appendix D. At the end, you will be able to estimate an interesting microscopic quantity: the
very small distance by which atoms shift in the lattice of BaTiO3 | in a ferroelectric transition.
The ability to estimate such a quantity is what makes this experiment especially interesting. List of physical quantities which you will be expected to extract, calculate and estimate from your data
(Some of these can be measured rather precisely; others only roughly estimated.)

In VO2

:
- The semiconducting gap Eg
- The resistance ratio between semiconducting and metallic phases
- Absolute resistivities in semiconducting and metallic phases
- The value of TC
- The coercive temperature T
∗
- The temperature of a percolation transition TM

In BaTiO3

:

- TC
- Relative dielectric constant k vs. T , from about 20 °C to 150 °C
- Curie–Weiss law at T > TC and Curie–Weiss constant CCW
- The value of a microscopic dipole moment p
- The effective atomic displacement x responsible for the appearance of p
- The last two quantities can be also calculated for BaTiO3 | single crystals using the literature
value of CCW
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

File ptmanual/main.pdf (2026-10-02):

## Phase Transitions: Metal–Insulator Transition in VO2

## and Ferroelectric Transition in BaTiO3

Advanced Laboratory
Department of Physics & Astronomy Stony Brook University
Write-up version of September 2026
Sections on ferroelectricity in BaTiO3 by Laszlo Mihaly and, in part, Michael Gurvitch; sections on phase-transition theory and the metal–insulator transition in VO2 by Michael Gurvitch.

## Contents

Pre-experiment and mid-experiment evaluation sheet | 4
1 How to prepare for the measurement | 5
2 Goals of the experiment | 5
3 Experimental set-up | 6
4 Principle of the measurement and an overview of data analysis | 6

### 5 Looking ahead: what should and should not be included in your Final Report 8

6 Measurement techniques | 9
7 The rest of the experimental apparatus in detail | 17
8 Suggested protocol for a measurement | 23
9 Advice for evaluating the capacitance data | 23
A Elements of AC circuit theory relevant to our measurements using the lock-in
amplifier | 25
B The four-probe method: advantages and limitations | 30
C Data taking with PyFERRO | 35
D Physics of phase transitions | 38

D.3.1 First-order transitions from the thermodynamic point of view; mixed-phase D.3.2 Second-order transitions from the thermodynamic point of view; elements

D.4.4 MIT in VO2
D.4.5 Development of a mixed state and hysteresis in VO2

D.6 Paraelectric to ferroelectric transition; Curie–Weiss law | 54
D.7 Derivation of CCW in terms of a microscopic dipole moment | 55
References | 59
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

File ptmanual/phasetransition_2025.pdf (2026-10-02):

## Advanced Laboratory

Dept. of Physics & Astronomy Stony Brook University

### Pre-experiment and mid-experiment evaluation sheet

You must meet with a staff member for the experiment you are doing before beginning an experiment and before the lab period indicted in the middle of the experiment for an evaluation of your preparation and your progress to date. This form must be signed and dated by the staff member to indicate you have done the required work to date. It must be attached as the first page of your report. You will lose
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

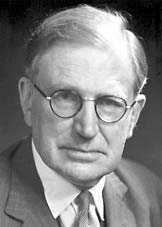
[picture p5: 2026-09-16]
ptmanual/figures/mott.png

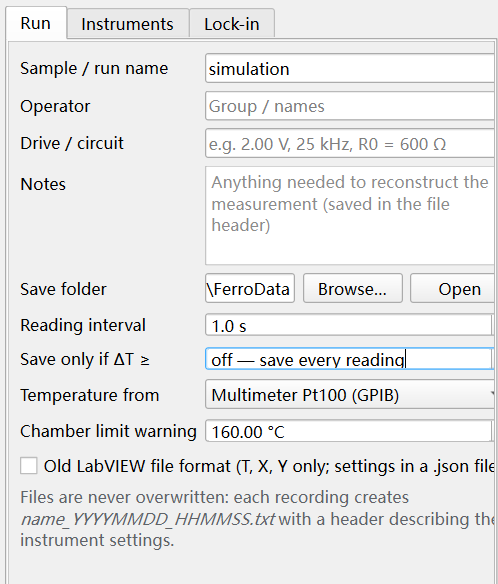
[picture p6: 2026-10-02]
ptmanual/figures/pyferro-run.png

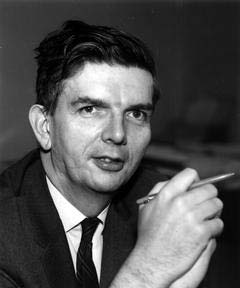
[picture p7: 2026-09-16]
ptmanual/figures/dicke.png

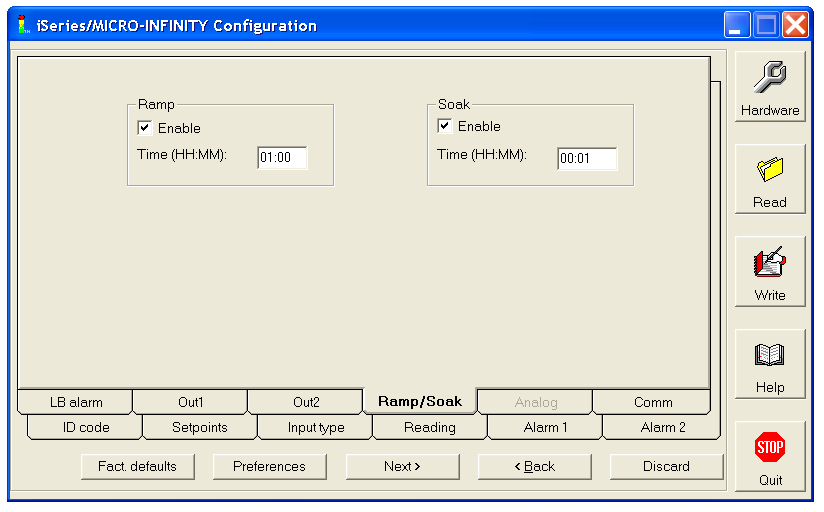
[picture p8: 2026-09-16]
ptmanual/figures/tc-rampsoak.png

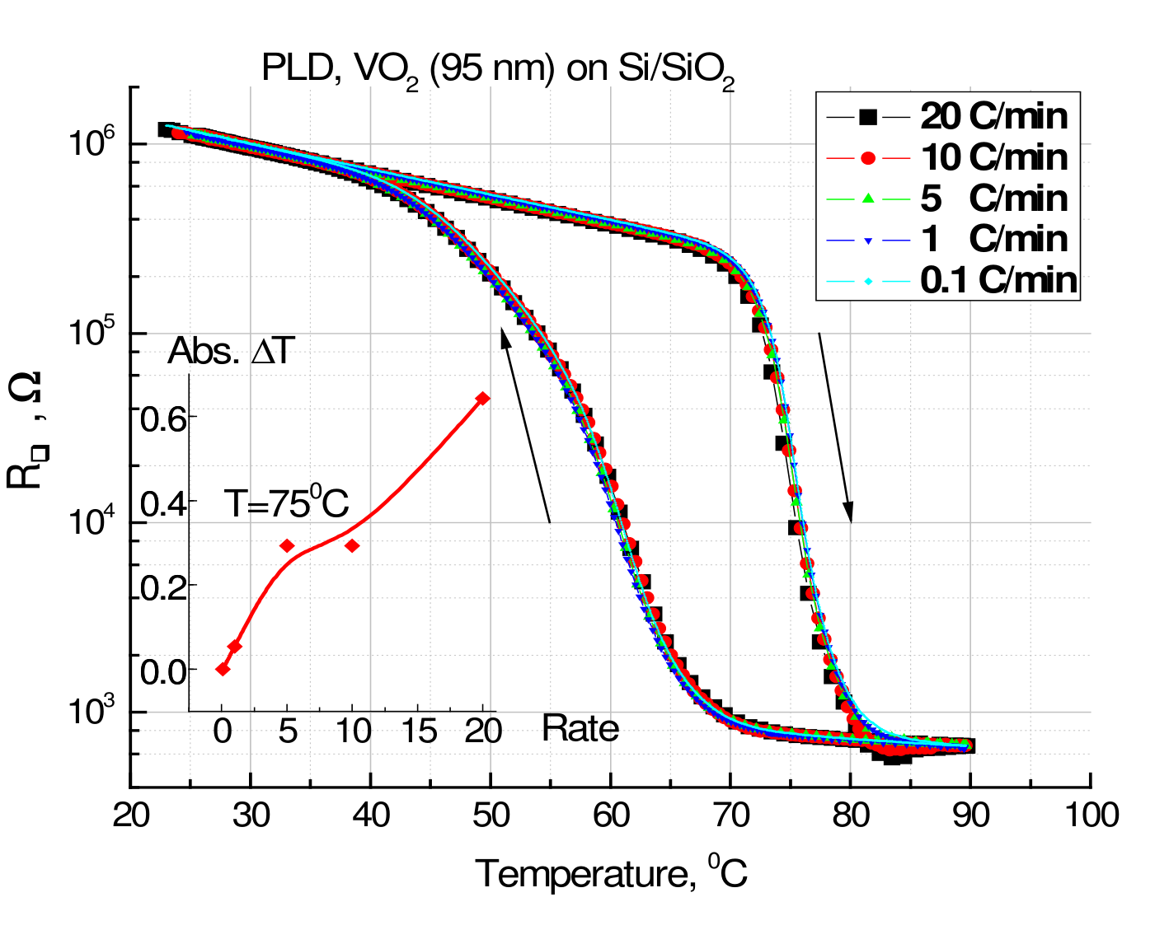
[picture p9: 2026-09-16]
ptmanual/figures/fig05-vo2-hysteresis.png

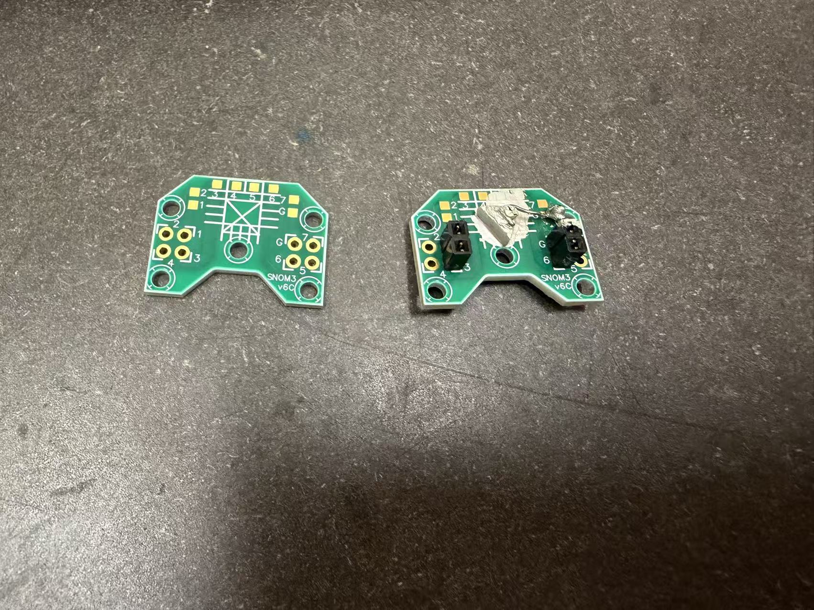
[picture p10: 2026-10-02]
ptmanual/figures/sample.png

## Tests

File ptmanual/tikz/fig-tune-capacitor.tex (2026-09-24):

% !TEX program = lualatex
\documentclass[border=6pt]{standalone}
\input{../tikzpreamble}
\begin{document}
\begin{tikzpicture}[every node/.style={font=\small}]
  \draw[line width=0.5pt] (0,-1.6) -- (0,1.7);
  \draw[line width=0.5pt] (-1.2,0) -- (5.2,0);
  \node[anchor=south west,font=\footnotesize] at (0.15,0.6) {Out-of-phase};
  \node[anchor=south east,font=\footnotesize] at (4.95,0.6) {In-phase};

  \coordinate (O)  at (0,0);
  \coordinate (VC) at (-14:4.0);            % V_C = V (measured)
  \coordinate (Vx) at (4.0*cos{-14},0);

  \draw[phasor] (O) -- (VC);
  \node[anchor=north west,font=\footnotesize] at (VC) {$V_C=V$};
  \draw[guide] (VC) -- (VC |- O);
  \draw[guide] (VC) -- (VC -| O);
  \node[anchor=south east,font=\footnotesize] at ($(VC|-O)+(0,0.05)$) {$V_1$};
  \node[anchor=north east,font=\footnotesize] at ($(VC-|O)+(-0.05,0)$) {$V_2$};
  \draw[line width=0.5pt] (0.95,0) arc[start angle=0,end angle=-14,radius=0.95];
  \node[font=\footnotesize] at (-7:1.25) {$\alpha$};
\end{tikzpicture}
\end{document}

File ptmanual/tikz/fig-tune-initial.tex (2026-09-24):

% !TEX program = lualatex
\documentclass[border=6pt]{standalone}
\input{../tikzpreamble}
\begin{document}
\begin{tikzpicture}[every node/.style={font=\small}]
  \draw[line width=0.5pt] (0,-1.0) -- (0,1.6);
  \draw[line width=0.5pt] (-1.1,0) -- (4.6,0);
  \node[anchor=south west,font=\footnotesize] at (0.15,0.55) {Out-of-phase};
  \node[anchor=north west,font=\footnotesize] at (3.55,-0.12) {In-phase};
  \draw[phasor] (0,0) -- (3.5,0);
  \node[anchor=south,font=\footnotesize] at (2.4,0.14) {$V_0=V$};
\end{tikzpicture}
\end{document}

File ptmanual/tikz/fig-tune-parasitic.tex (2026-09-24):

% !TEX program = lualatex
\documentclass[border=6pt]{standalone}
\input{../tikzpreamble}
\begin{document}
\begin{tikzpicture}[every node/.style={font=\small}]
  \draw[line width=0.5pt] (0,-1.3) -- (0,1.9);
  \draw[line width=0.5pt] (-1.2,0) -- (5.0,0);
  \node[anchor=south west,font=\footnotesize] at (0.15,0.85) {Out-of-phase};
  \node[anchor=north east,font=\footnotesize] at (5.0,-0.55) {In-phase};

  \coordinate (O)  at (0,0);
  \coordinate (VC) at (4.0,0);
  \coordinate (VR) at (0,0.95);
  \coordinate (V0) at (4.0,0.95);

  \draw[phasor] (O) -- (VC);
  \node[anchor=north east,font=\footnotesize] at (3.95,-0.16) {$V_C=V$};
  \draw[phasor] (O) -- (VR);
  \node[anchor=east,font=\footnotesize] at (-0.12,0.85) {$V_R$};
  \draw[phasor] (O) -- (V0) node[anchor=south east,font=\footnotesize,inner sep=2pt] {$V_0$};
  \draw[guide] (V0) -- (VC);
  \draw[line width=0.5pt] (1.6,0) arc[start angle=0,end angle=13.4,radius=1.6];
  \node[font=\footnotesize] at (7:1.95) {$\alpha$};
\end{tikzpicture}
\end{document}

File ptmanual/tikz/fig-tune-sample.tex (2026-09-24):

% !TEX program = lualatex
\documentclass[border=6pt]{standalone}
\input{../tikzpreamble}
\begin{document}
\begin{tikzpicture}[every node/.style={font=\small}]
  \draw[line width=0.5pt] (0,-1.7) -- (0,2.0);
  \draw[line width=0.5pt] (-1.2,0) -- (6.2,0);
  \node[anchor=south west,font=\footnotesize] at (0.6,1.35) {Out-of-phase};
  \node[anchor=west,font=\footnotesize] at (5.3,0.28) {In-phase};

  \coordinate (O)   at (0,0);
  \coordinate (VCp) at (-13:4.1);           % V_{C'} = V (measured)
  \coordinate (VR)  at (77:1.35);
  \coordinate (V0)  at ($(VCp)+(VR)$);

  \draw[phasor] (O) -- (VCp) node[anchor=north west,font=\footnotesize,inner sep=2pt] {$V_{C'}=V$};
  \draw[phasor] (O) -- (VR);
  \node[anchor=east,font=\footnotesize] at (-0.12,1.15) {$V_R$};
  \draw[phasor] (O) -- (V0)  node[anchor=south east,font=\footnotesize,inner sep=2pt] {$V_0$};
  \draw[guide] (VR) -- (V0) -- (VCp);
  \draw[guide] (V0) -- (V0 |- O);

  \draw[line width=0.5pt] (1.85,0) arc[start angle=0,end angle=18.5,radius=1.85];
  \node[font=\footnotesize] at (9:2.15) {$\beta$};
  \draw[line width=0.5pt] (2.75,0) arc[start angle=0,end angle=-13,radius=2.75];
  \node[font=\footnotesize] at (-6.5:3.1) {$\varphi$};
\end{tikzpicture}
\end{document}

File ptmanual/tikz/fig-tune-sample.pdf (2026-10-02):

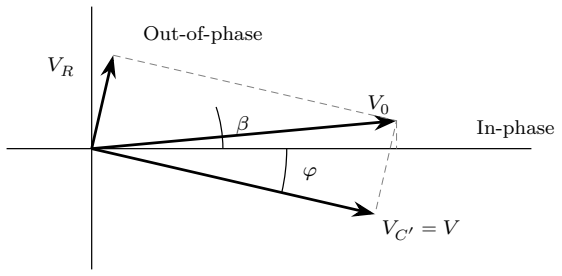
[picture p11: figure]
Out-of-phase; In-phase

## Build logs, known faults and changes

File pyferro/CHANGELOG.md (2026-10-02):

# Changelog

Versions follow `MAJOR.MINOR.PATCH`. Each release is tagged `v<version>` in git, and
the same number appears in the window title and in every data-file header
(`# software: pyferro <version>`), so a saved measurement can always be traced back
to the code that produced it. The number is written in exactly one place,
`__version__` in `ferro/__init__.py`; see "Versioning and releases" in
[README.md](README.md).

## Unreleased

### Added
- **The Lock-in tab, the lab-manual check and *Lab-manual values* work for the SR830.**
  PyFERRO reads its whole set-up (reference, sine output level and frequency, input,
  coupling, grounding, line notches, reserve, filter slope, displays, phase) for the
  Test button, the data-file header and the once-a-minute check, compares it with the
  lab manual's new SR830 table, and can set any of it from the Lock-in tab, during a run
  too. An offset or expand can be turned off from the tab, not on.
- The Lock-in tab rebuilds its controls for the model chosen on the Instruments tab.

### Changed
- **The SR830 is now the default lock-in**, at GPIB address 8, and the lab manual
  describes only the SR830. The 5302 is still supported: its checks now name it "the
  5302 capacitance set-up", the values of the manual's former 5302 table. A settings
  file that already names a model keeps it: choose *SRS SR830* once on the Instruments
  tab.
- Choosing a lock-in model moves the address to that model's on this rig (8 for the
  SR830, 12 for the 5302), unless the address was typed in by hand.
- The lab-manual set-up that *Test lock-in*, the recording check and *Lab-manual values*
  use now matches the manual's revised 5302 table: oscillator level 0.500 V (was
  1.000 V) and the preamplifier as signal input (was DIRECT INPUT). A lock-in set the
  old way is now reported as differing from the lab manual.

## 1.1.0 — 2026-09-30

### Added
- **Choice of lock-in and multimeter model** on the Instruments tab. The lock-in can be
  an EG&G 5302 (this rig, the default) or an SRS SR830; the multimeter
  an HP 34401A (the default) or a Keithley 199. The choice is saved with the other
  settings, used in simulation, shown by the Test buttons and in the log, and written
  into every data file header (`# lockin_model:`, `# temperature_source:`). The SR830
  and Keithley 199 manuals are in `docs/manuals/`.
- The SR830 is read over GPIB with one query for X, Y, R and θ together. Its overload
  status latches, so an overload between two samples still flags the later one; a
  status read that needed a retry flags the sample too, since the retry may have missed
  the latched bits. It
  answers in volts, so there is no scaling. Its output offset and expand are read with
  every sample and logged when set (including when already set at the start), because the manual does not say whether the values
  read include them.
- The Keithley 199 has no `*IDN?`; its status word identifies it. It is set to ohms on
  every connection, with Zero turned off, because opening the connection resets it to
  its saved defaults. An overload is reported
  as an error, not recorded as a huge resistance, and a reading in the wrong function
  (someone changed it on the front panel) is refused.
- Flag **16** in the data file: temperature discarded just after connecting.
- **The 5302's front-panel set-up is read over GPIB**: reference mode, oscillator level
  and frequency, dynamic reserve, filter, signal input and reference phase. The Test
  button shows them and every data file header records them, so a file says how the
  lock-in was set. The lab manual has a matching 5302 settings table, with how to set
  each one.
- **A Lock-in tab sets the 5302 from the program**: reference, oscillator frequency and
  level, sensitivity, expand, time constant, filter, reserve and input. *Lab-manual
  values* fills in the lab manual's table; *Apply* lists the commands, asks, sends only
  what differs and reads the settings back. During a run the change is sent between
  samples by the measurement loop and written into the data file. Checked on the rig
  during a real run.
- **All of the 5302's settings are recorded during a run**: every minute (and at once
  after a change from the Lock-in tab) the reference, oscillator, filter, reserve, input
  and phase are read with the time constant, and any change becomes a `#` line in the
  file, as sensitivity and time-constant changes already did.
- **Test lock-in checks the 5302 against that table**: a table under the result shows
  each setting now, the lab manual's value, and for anything that differs, which key
  changes it. Starting a recording logs any differences as a warning and writes them
  into the header (`# lockin_setup_check:`). **Test controller** also shows output 2,
  whether output 1 is limited below 100 %, and the setpoint mode and ramp rate.
- **`pixi run start` updates itself first** with `git pull --ff-only`, so the lab PC's
  clone always runs the latest code. Being offline, a local edit that blocks the pull,
  or a folder that is not a git clone never stops the program starting.
  `pixi run start --skip-deps` starts without updating.
- **`pixi run gpib`** (`tools/gpib_check.py`) diagnoses the lock-in's GPIB link one
  step at a time — VISA library, listeners on the bus (without MAX or admin rights),
  serial poll, `ID` under each terminator pair, then twenty fresh connections — and ends
  in a one-line verdict with a success rate.

### Changed
- **Installing on the lab PC is now a git clone run with pixi**, not the offline bundle:
  the README's install section, troubleshooting and the lab manual describe that route.
- Releasing is now by hand — test, commit, tag, push (README §9) — since there is no
  longer a bundle to build.
- The lab manual's data-taking appendix describes PyFERRO instead of the LabVIEW
  routine, and its suggested protocol and temperature-measurement section follow.

### Removed
- **The offline Windows bundle and its packaging** (`packaging/`: `build_offline.sh`,
  `release.sh`, `INSTALL.bat` and the `.bat` launchers), with its README section and
  tests. The lab PC has internet and runs the git clone, so nothing uses it.

### Fixed
- **The window ran off the right of the screen.** It opened at a fixed 1400 px, wider
  than the lab PC's 1280 px screen, and once recording started the banner's file path
  forced it to about 2600 px, since a window never goes narrower than its widest label.
  It now opens at the screen's size when that is smaller, and the banner has its own
  line and shortens the middle of the path ("…"), with the full path as its tooltip.
- **Heating and cooling were split badly when the temperature wobbles.** The tracker
  used a 60 s slope, and a wobble of a few degrees in the readings flipped it on every
  swing, recolouring the curves and counting a new
  segment each time. It now averages over 120 s and turns only once the average has come
  back 3 °C from the highest (or lowest) point reached. On synthetic runs with ±5 °C
  swings of period 5–120 s it turns exactly once, at the true peak; the old tracker
  turned up to hundreds of times. A turn is recognised a minute or two late, so the
  plot recolours the points back to the peak and the file gets a
  `# Ramp turned to cooling at … °C, t = … s` line. The `direction` column's 0 now
  means "not yet known" only; there is no separate "steady".
- **After Clear plots, nothing new appeared on the plots.** Zooming or dragging a plot
  switches its auto-range off, which pins the view to the old time window; once the old
  points were cleared, every new one landed off-screen, so it looked as if nothing was
  recorded. The data file was unaffected. Clear plots now turns auto-range back on.
- **Temperatures of about −3000 °C at the start of a run** squashed the plot. A status
  word from the controller outside the five fault codes the manual lists (8000H decodes
  to −3276.8 °C) was read as a temperature. Anything below −999.9 °C, lower than any
  input can measure, is now reported as a controller fault instead. And the first 3
  temperatures after the controller or multimeter connects, at the start or on a
  reconnect, are discarded: `nan` in the file with flag 16, left out of the plot.
- **Connecting to the lock-in, and the Test button, timed out.** The app asked for a
  query's reply the instant it had sent the query; the 5302 had not finished parsing it,
  so the reply came late and landed on the next query (`SEN answered 5302`), after which
  every attempt failed. The lock-in is now given 50 ms between the query and the read.
  Against the real instrument the connect-and-test path went from 0 of 10 to 15 of 15,
  and 60 of 60 samples were read with no retries.

## 1.0.2 — 2026-09-17

### Fixed
- **Y was scaled wrongly whenever Expand was on.** Expand multiplies the gain of the x
  channel only (manual sections 4 and 9), but Y was divided by ten as well, so Y read
  ten times too small. Files recorded with the EX indicator lit have Y wrong by that
  factor; X was right.
- A dropped reply to `EX` no longer switches expand detection off for the rest of the
  connection. That fallback assumed expand was off, which would have read X ten times
  too large without a warning; the sample is now recorded as missing instead.
- The lock-in's terminator search no longer retries each attempt, so a silent
  instrument no longer holds up Stop and the reading loop for about a minute.
- The offline installer could not run on a clean Windows machine. Three separate
  faults, all in the packaging rather than the program:
  - The Windows launchers shipped with Unix line endings, which `cmd.exe` mis-parses.
    They are now written with CRLF, `.gitattributes` keeps them that way, and a test
    fails if a bare newline gets back in.
  - `pixi-unpack.exe` is an MSVC build and needs `VCRUNTIME140.dll`, which a bare
    Windows install does not have and which otherwise means an admin-rights
    redistributable. The bundle now carries that DLL — taken from the same
    environment it unpacks — next to the unpacker, where Windows looks first.
  - `INSTALL.bat` reported `The system cannot find the path specified` when it was
    run from inside Explorer's zip viewer, which copies only that one file. It now
    checks for each piece it needs and says which is missing, listing what it did
    find, and catches the network-share case that `cd /d` cannot handle.
- Plot colours no longer misrepresent the ramp. Points recorded before the ramp
  direction is established, and any hold at setpoint, were carried forward as the
  previous direction — so the start of every run was drawn as "heating" whatever it was
  doing. Steady readings now have their own neutral curve, matching the `direction`
  column in the data file.
- The heating and cooling branches cover the same temperature range, so the cooling
  curve was drawn over the heating one and hid it. Cooling is now dashed and slightly
  transparent, leaving both readable where they overlap.
- Temperature vs time is coloured by ramp direction as well — the one plot where the
  branches cannot overlap.

## 1.0.1 — 2026-09-16

### Fixed
- Recording on macOS: the default save folder is now `~/FerroData`. `~/Documents` is
  protected by macOS privacy, and recording there failed with "Operation not permitted".
- The save-folder check no longer refuses a folder that allows writing but not deleting,
  uses a uniquely named probe file, and its message names the macOS privacy setting.
- Dark mode: the readout tiles and the log kept their text colour from the system theme,
  giving white text on the light tiles. The window now follows the system theme, and the
  tiles, the log panel and the plots use a matching light or dark colour set.

### Added
- A session log, written from start-up to `~/.ferro/logs/pyferro_<start>.log`, holding
  every message the log panel shows — including set-up problems from before recording
  began. Each data file names it in its header (`# session_log:`) and gets a copy beside
  it (`<name>.log`) when the recording closes. The twenty newest logs are kept.

- Events that change what the numbers mean are now logged **and written into the data
  file** as `#` comment lines: lock-in sensitivity, expand and overload changes, time
  constant and reference frequency changes, controller mode or RUN/STOP changes,
  reading interval, ΔT threshold, chamber limit, temperature source, and edits to the
  run name, operator, drive and notes.
- Instruments now report recovery ("answering again after 12 s") and reconnection
  attempts, not only the first failure.
- The header of every data file names the port each instrument used
  (`# connection_lockin:`, `# connection_pid:`), and the same lines are logged when a run
  starts, so files from different rigs can be told apart.
- The session log records the machine, Python and library versions at start-up, and a
  closing line, so a log that ends abruptly means a crash rather than a normal exit.

### Changed
- *Temperature from* can be changed while monitoring and is locked only while recording,
  so a single file keeps one temperature source. The multimeter is opened on demand when
  it is selected during a run.

## 1.0.0 — 2026-09-16

First Python release, replacing the LabVIEW routine `FERRO v.2.vi`.

### Added
- Acquisition of lock-in X/Y and sample temperature with live plots, recording that
  can be switched on and off during a run, and files that are never overwritten.
- EG&G 5302 lock-in driver over GPIB or RS-232, reading the sensitivity (and expand)
  back from the instrument before every reading.
- Omega CND3 (Delta DT340) temperature-controller driver over RS-485 Modbus
  ASCII/RTU, read-only, with auto-detection of the serial settings.
- Optional HP 34401A multimeter as a second Pt100 thermometer (IEC 60751 conversion).
- Simulation mode for practice and testing without hardware.
- Data files with a metadata header, plus columns for time, R/θ, setpoint,
  ramp direction, segment number and per-instrument error flags; an option writes the
  old three-column LabVIEW format instead.
- Offline Windows bundle built with pixi and pixi-pack, including the instrument
  manuals and the wiring diagram.
- Tests: instrument drivers, wire-level protocol tests over a virtual serial port
  (checked against the frames printed in the manuals), data files and the GUI.

### Fixed compared with the LabVIEW routine
- Lock-in readings are scaled using the sensitivity read from the instrument, instead
  of a stored value that could drift out of step (the likely cause of X values stuck
  at 1.00 × 10⁻⁷ V in the 2025 BaTiO₃ data).
- A failed instrument read no longer stops a run: the value is recorded as `nan`,
  flagged, and the connection is reopened automatically.

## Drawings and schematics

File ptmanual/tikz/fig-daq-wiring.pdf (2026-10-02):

### Lock-in amplifier

### PID controller

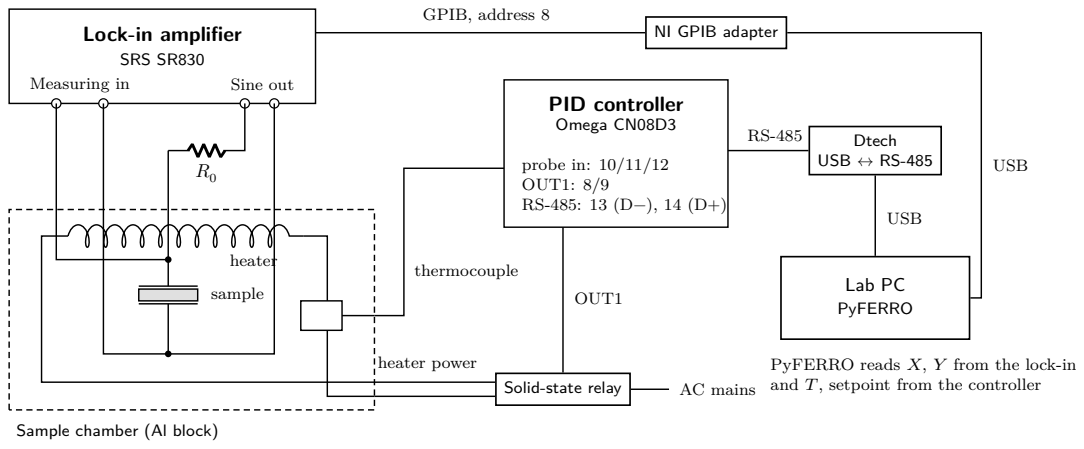
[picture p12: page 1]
SRS SR830; Measuring in; Sine out; heater sample; Omega CN08D3; probe in: 10/11/12 OUT1: 8/9 RS-485: 13 (D−), 14 (D+); thermocouple; heater power; OUT1; AC mains; Lab PC PyFERRO; Dtech USB ↔ RS-485; USB; GPIB, address 8

NI GPIB adapter

PyFERRO reads X, Y from the lock-in
and T, setpoint from the controller

Solid-state relay

Sample chamber (Al block)

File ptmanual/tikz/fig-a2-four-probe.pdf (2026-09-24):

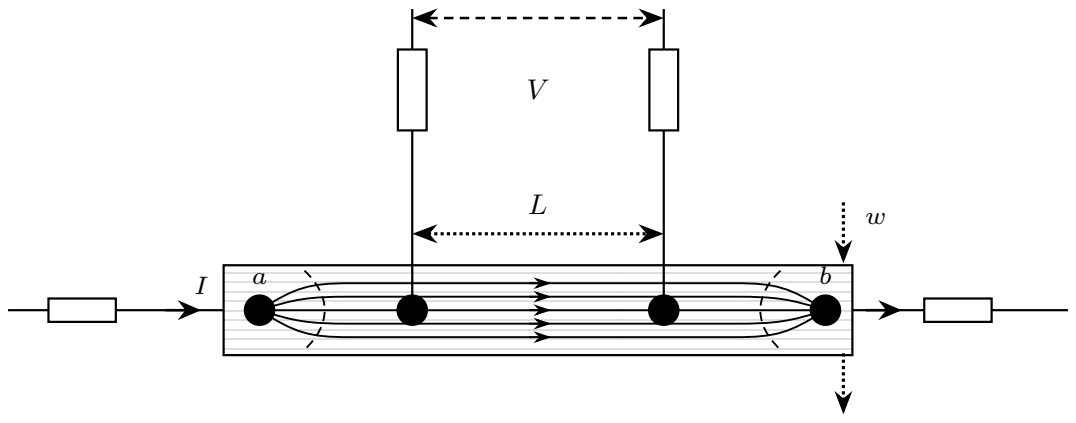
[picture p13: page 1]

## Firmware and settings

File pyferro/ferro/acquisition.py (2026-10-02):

"""Acquisition engine: owns the instruments and the measurement loop.

Runs in a background thread and reports through plain callbacks, so it is
GUI-independent (the Qt window wraps the callbacks in signals).

Robustness rules:
* A failed instrument read never stops the run - that value becomes NaN, a flag
  bit is set in the file, and the instrument is reopened after repeated failures.
* Recording can be switched on/off while monitoring (like the old "Save" button);
  each recording goes to a new, never-overwritten file.
"""

from __future__ import annotations

import math
import threading
import time
import traceback
from dataclasses import dataclass
from typing import Callable

from . import __version__, sessionlog
from .analysis import DirectionTracker
from .config import AppConfig
from .datafile import (
    FLAG_DMM_ERROR,
    FLAG_LOCKIN_ERROR,
    FLAG_LOCKIN_OVERLOAD,
    FLAG_PID_ERROR,
    FLAG_TEMP_DISCARDED,
    DataWriter,
    unique_path,
)
from .instruments.cnd3 import CND3, PIDError
from .instruments.hp34401a import HP34401A
from .instruments.keithley199 import Keithley199
from .instruments.lockin5302 import Lockin5302, check_setup
from .instruments.sr830 import SR830
from .instruments import simulated
from .transports import (TERMINATIONS, SerialTransport, TransportError, VisaTransport,
                         probe_terminations)

NAN = float("nan")
DISCARDED = object()  # what _read returns for a reading thrown away just after connecting
REOPEN_AFTER_FAILURES = 3
REOPEN_BACKOFF_S = 5.0
POLL_SETTINGS_S = 60.0  # how often to re-read settings that are not read every sample
BEHIND_WARN_S = 30.0  # how often to say the loop cannot keep up with the interval
LOCKIN_GAP_S = 0.05  # the 5302 loses a command sent while it is still busy
LOCKIN_RETRIES = 2  # the GPIB link on this rig drops the odd exchange
# Temperatures thrown away after each (re)connect: the first ones can be nonsense
# (-3000 C spikes on the CND3) and would squash the plot's temperature axis.
DISCARD_TEMPERATURES_AFTER_OPEN = 3

# Config value -> driver. The SR830 and the Keithley 199 are opened with the
# terminators their manuals give; the 5302 with the terminator search.
LOCKIN_MODELS = {"5302": Lockin5302, "sr830": SR830}
DMM_MODELS = {"34401a": HP34401A, "k199": Keithley199}


# Lock-in settings watched by the poll: (settings key, name in the file, format,
# relative change that counts, or None for any change).
LOCKIN_WATCHED = (
    ("time_constant", "time constant", str, None),
    ("frequency_hz", "reference frequency", lambda v: f"{v:.4g} Hz", 1e-3),
    ("reference_mode", "reference", str, None),
    ("oscillator_hz", "oscillator frequency", lambda v: f"{v / 1000:.4g} kHz", 1e-3),
    ("oscillator_v", "oscillator level", lambda v: f"{v:.3f} V", 5e-3),
    ("dynamic_reserve", "dynamic reserve", str, None),
    ("filter", "filter", str, None),
    ("signal_input", "signal input", str, None),
    ("coupling", "input coupling", str, None),
    ("grounding", "input grounding", str, None),
    ("line_filter", "line notch filters", str, None),
    ("filter_slope", "filter slope", str, None),
    ("display", "displays", str, None),
    ("phase_deg", "reference phase", lambda v: f"{v:.1f}°", None),
)


def _differs(before, now, rel) -> bool:
    if rel is None:
        return before != now
    return abs(now - before) > rel * max(abs(before), abs(now), 1e-12)


# Terminator pairs that have worked, by resource: a reconnect should not pay for
# the whole search again.
_DETECTED_TERMINATIONS: dict[str, tuple] = {}


# --- instrument factories (also used by the GUI "Test" buttons) ------------
def open_lockin(cfg: AppConfig, on_log: Callable[[str, str], None] | None = None,
                should_stop: Callable[[], bool] | None = None):
    c = cfg.lockin
    driver = LOCKIN_MODELS.get(c.model)
    if driver is None:
        raise TransportError(f"Unknown lock-in model {c.model!r}")
    if cfg.simulate:
        return driver(simulated.lockin_transport(c.model, simulated.shared_sample()))
    if driver is SR830:
        return _open_sr830(c, on_log)
    if c.interface == "serial":
        if not c.serial_port:
            raise TransportError("No RS-232 port selected for the lock-in")
        return driver(SerialTransport(c.serial_port, baudrate=c.baudrate, timeout_s=c.timeout_s))

    # The 5302's terminator is set on its own front panel and the wrong guess times
    # out exactly like a dead instrument, so try each pair until ID answers.
    # Probe with a short timeout: a silent instrument otherwise costs the full
    # timeout eight times over, on the acquisition thread, which is what a Stop
    # press has to wait for. Whatever worked is tried first next time, so a
    # reconnect mid-run costs one attempt rather than eight.
    order = list(TERMINATIONS)
    known = _DETECTED_TERMINATIONS.get(c.resource)
    if known in order:
        order.insert(0, order.pop(order.index(known)))
    probe_timeout = min(c.timeout_s, 1.0)

    # No retries while probing: a wrong pair has to fail fast, and Stop is only checked
    # between pairs. Retries go on once the link is known to work.
    def open_one(write_t, read_t):
        return VisaTransport(c.resource, timeout_s=probe_timeout, gap_s=LOCKIN_GAP_S, retries=0,
                             reply_delay_s=LOCKIN_GAP_S,
                             write_termination=write_t, read_termination=read_t)

    def answers_id(transport):
        try:
            return driver(transport).check()
        except Exception:
            return driver(transport).check()  # one retry: the first command can be lost

    transport, label = probe_terminations(
        open_one, answers_id, name=f"Lock-in {c.resource}",
        terminations=order, should_stop=should_stop)
    _DETECTED_TERMINATIONS[c.resource] = transport.terminators
    transport.set_timeout(c.timeout_s)
    transport.retries = LOCKIN_RETRIES
    if on_log:
        on_log("info", f"Lock-in {c.resource}: answered with {label}")
    return driver(transport)


def _open_sr830(c, on_log) -> SR830:
    if c.interface == "serial":
        raise TransportError("The SR830 is supported over GPIB only - choose GPIB as the connection")
    # LF both ways (manual 5-1, 5-2), and no gap or reply delay: the SR830 buffers
    # commands and holds off the bus itself.
    transport = VisaTransport(c.resource, timeout_s=c.timeout_s, retries=LOCKIN_RETRIES,
                              write_termination="\n", read_termination="\n")
    try:
        li = SR830(transport)
        li.check()
    except Exception:
        transport.close()
        raise
    if on_log:
        on_log("info", f"Lock-in {c.resource}: SR830 answered")
    return li
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

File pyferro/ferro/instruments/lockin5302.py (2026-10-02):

"""EG&G / PAR Model 5302 lock-in amplifier.

Command reference: 5302 Instruction Manual (221490-A-MNL-F), chapter 9.

* ``XY``  -> two integers, full scale = +/-10000 (range +/-12000)
* ``SEN`` -> sensitivity index 0..21 (100 nV .. 1 V, 1-2-5 sequence)
* ``EX``  -> 1 when Expand X is on: the x channel's gain x10, y unaffected
* ``XTC`` -> output time-constant index 0..18
* ``FRQ`` -> reference frequency in mHz
* ``ID``  -> "5302"
* ``IE``, ``OA``, ``OF``, ``DR``, ``FLT``, ``PREAMP``, ``P`` -> the front-panel set-up
  (reference, oscillator level and frequency, reserve, filter, input, phase), read by
  ``setup()`` for the Test button, the file header and the once-a-minute poll

Volts are computed as ``counts / 10000 * full_scale`` using the sensitivity read
back from the instrument, so changing SEN on the front panel mid-run (or an
auto-sensitivity step) is picked up automatically.

The same commands with a number set the value. ``apply()`` sends the ones in
``SETTABLE`` (the Lock-in tab), and ``check_setup()`` compares the settings with
``CAPACITANCE_SETUP``, the 5302 capacitance set-up. ``check_setup``, ``commands_for``
and ``SetupCheck`` are shared with the SR830 driver.
"""

from __future__ import annotations

import math
import re
from dataclasses import dataclass

from ..transports import Transport, TransportError

SENSITIVITIES_V = [
    100e-9, 200e-9, 500e-9,
    1e-6, 2e-6, 5e-6,
    10e-6, 20e-6, 50e-6,
    100e-6, 200e-6, 500e-6,
    1e-3, 2e-3, 5e-3,
    10e-3, 20e-3, 50e-3,
    100e-3, 200e-3, 500e-3,
    1.0,
]
SENSITIVITY_LABELS = [
    "100 nV", "200 nV", "500 nV", "1 µV", "2 µV", "5 µV", "10 µV", "20 µV", "50 µV",
    "100 µV", "200 µV", "500 µV", "1 mV", "2 mV", "5 mV", "10 mV", "20 mV", "50 mV",
    "100 mV", "200 mV", "500 mV", "1 V",
]
TIME_CONSTANTS_S = [
    float("nan"), 100e-6, 1e-3, 10e-3, 20e-3, 50e-3, 100e-3, 200e-3, 500e-3,
    1, 2, 5, 10, 20, 50, 100, 200, 500, 1000,
]
TIME_CONSTANT_LABELS = [
    "F MIN", "F 100 µs", "F 1 ms", "F 10 ms", "20 ms", "50 ms", "100 ms", "200 ms",
    "500 ms", "1 s", "2 s", "5 s", "10 s", "20 s", "50 s", "100 s", "200 s", "500 s",
    "1000 s",
]
# Front-panel set-up, read back so the Test button and the data file show how the
# instrument was set (manual ch. 9: IE, DR, FLT, PREAMP). AC/DC coupling and
# FLOAT/GND are latching front-panel keys with no GPIB command, so they cannot be read.
REFERENCE_MODES = {0: "INT", 1: "TTL", 2: "EXT"}
RESERVE_MODES = {0: "MIN", 1: "HI STAB", 2: "NORM", 3: "HI RES 1", 4: "HI RES 2"}
FILTER_MODES = {0: "FLAT", 1: "NOTCH", 2: "LOW-PASS", 3: "BAND-PASS", 4: "HI-PASS"}
SIGNAL_INPUTS = {0: "DIRECT", 1: "PREAMP"}


def _volts(v) -> str:
    return f"{v:.3f} V"


def _khz(v) -> str:
    return f"{v / 1000:.3f} kHz"


def _on_off(v) -> str:
    return "on" if v else "off"


# The 5302 set-up for the capacitance measurement. It was the lab manual's 5302 table
# (tab:lockin5302) until the manual moved to the SR830 and dropped the 5302
# (2026-10-02); that table is in ptmanual/main.tex's git history.
# (settings key, name, wanted - a tuple means any of them, formatter, how to change it)
CAPACITANCE_SETUP = (
    ("reference_mode", "Reference", "INT", str, "REF, the rightmost key under the display"),
    ("oscillator_hz", "Oscillator frequency", 25000.0, _khz, "OSC F with the setting knob"),
    ("oscillator_v", "Oscillator level", 0.5, _volts, "OSC V with the setting knob"),
    ("sensitivity", "Sensitivity", "1 V", str, "the left SEN key"),
    ("expand", "Expand", False, _on_off, "FUNCT, then SEN/EXPAND"),
    ("time_constant", "Time constant", ("500 ms", "200 ms"), str, "the TC keys"),
    ("filter", "Filter", "FLAT", str, "FILT, second key from the right under the display"),
    ("dynamic_reserve", "Dynamic reserve", "HI STAB", str, "the DYNRES/LOCAL key"),
    ("signal_input", "Signal input", "PREAMP", str, "the SIGNAL SETUP screen"),
)


def oscillator_level_command(volts: float) -> str:
    """OA n1 n2 for a level in volts (manual ch. 9: 5 mV to 5 V in three ranges)."""
    if not 0.005 <= volts <= 5.0:
        raise ValueError(f"oscillator level {volts:g} V is outside 5 mV to 5 V")
    n2 = 0 if volts <= 0.05 else 1 if volts <= 0.5 else 2  # finest range that holds it
    return f"OA {round(volts * 10 ** (5 - n2))} {n2}"


def oscillator_frequency_command(hz: float) -> str:
    """OF n1 n2 for a frequency in Hz: n1 = 1000..10000 across the decade n2 (1 mHz-1 MHz)."""
    if not 0.001 <= hz <= 1e6:
        raise ValueError(f"oscillator frequency {hz:g} Hz is outside 1 mHz to 1 MHz")
    n2 = min(8, int(math.floor(math.log10(hz) + 1e-9)) + 3)
    return f"OF {round(hz / 10 ** (n2 - 6))} {n2}"


def _code(names: dict, value: str) -> int:
    for code, name in names.items():
        if name == value:
            return code
    raise ValueError(f"{value!r} is not one of {', '.join(names.values())}")


# What apply() can set, in the order it sends them. The time constant goes before the
# reserve: a FAST time constant forces MIN reserve (manual 4.3), undoing a reserve set
# first. (settings key, command builder, description of the new value)
SETTABLE = (
    ("signal_input", lambda v: f"PREAMP {_code(SIGNAL_INPUTS, v)}", lambda v: f"input {v}"),
    ("reference_mode", lambda v: f"IE {_code(REFERENCE_MODES, v)}", lambda v: f"reference {v}"),
    ("oscillator_hz", oscillator_frequency_command, lambda v: f"oscillator {_khz(v)}"),
    ("oscillator_v", oscillator_level_command, lambda v: f"oscillator {_volts(v)}"),
    ("sensitivity_index", lambda v: f"SEN {int(v)}",
     lambda v: f"sensitivity {SENSITIVITY_LABELS[int(v)]}"),
    ("expand", lambda v: f"EX {1 if v else 0}", lambda v: f"expand {_on_off(v)}"),
    ("time_constant_index", lambda v: f"XTC {int(v)}",
     lambda v: f"time constant {TIME_CONSTANT_LABELS[int(v)]}"),
    ("dynamic_reserve", lambda v: f"DR {_code(RESERVE_MODES, v)}", lambda v: f"reserve {v}"),
    ("filter", lambda v: f"FLT {_code(FILTER_MODES, v)}", lambda v: f"filter {v}"),
)


def commands_for(changes: dict, settable=SETTABLE) -> list[tuple[str, str]]:
    """(command, description) for each setting in ``changes``, in sending order.

    Raises ValueError, before anything is sent, if any value is out of range.
    """
    out = []
    for key, command, describe in settable:
        if key in changes:
            out.append((command(changes[key]), describe(changes[key])))
    unknown = set(changes) - {key for key, _, _ in settable}
    if unknown:
        raise ValueError(f"cannot set {', '.join(sorted(unknown))}")
    return out
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

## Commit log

2026-09-16 PyFERRO 1.0.0: Python replacement for the LabVIEW FERRO routine
    Adds pyferro/, the acquisition program for the PHY445 phase-transition lab:
    EG&G 5302 lock-in over GPIB, Omega CND3 temperature controller over RS-485
    Modbus (read-only), optional HP 34401A Pt100 thermometer, live plots,
    crash-safe data files, simulation mode, tests including wire-level protocol
    tests, and an offline Windows bundle built with pixi/pixi-pack.
    Also adds ptmanual/, the LaTeX lab manual, now including the instrument
    wiring diagram (tikz/fig-daq-wiring.tex).
    [acquisition.py, analysis.py, cnd3.py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]
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2026-09-16 Fix the macOS save folder, dark-mode text and the temperature-source lock
    - Default save folder on macOS is ~/FerroData: ~/Documents is protected by
    macOS privacy (TCC) and recording there failed with EPERM.
    - check_writable() replaces the inline probe: unique probe name, cleanup
    failure ignored, and the message names the macOS privacy setting.
    - The window uses an explicit light palette and the readout tiles and log
    set their own colours, so a dark system theme no longer paints white text
    on the light tiles.
    - 'Temperature from' is editable while monitoring and locked only while
    recording; the multimeter is opened on demand if selected mid-run.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
    [acquisition.py, config.py, datafile.py]
2026-09-16 Log the whole session to a file, not just the recording
    The log panel was transient, so the messages that explain a run - an instrument
    that never answered, an auto-detect that found nothing, a refused save folder -
    were lost, and they usually happen before recording starts.
    ferro/sessionlog.py writes every message to ~/.ferro/logs/pyferro_<start>.log
    from start-up. Each data file names it in its header and receives a copy as
    <name>.log when the recording closes. Failures to write the log are ignored so
    they can never interrupt a measurement; the twenty newest logs are kept.
    [acquisition.py, sessionlog.py]
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2026-09-16 Write core messages to the session log directly
    The acquisition core reached the session log only through the GUI, so a run
    driven without a window left a data file whose own annotations were missing
    from its log. Acquisition now writes every message to the session log itself,
    and MainWindow.log() no longer re-writes bridged messages.
    [acquisition.py]
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2026-09-17 Stop simulation mode surviving a restart
    --simulate set cfg.simulate, the setup panel saved the whole config, and
    from_dict read the flag back on the next launch. So one practice run left
    every later start simulated, with nothing on the command line to explain
    the banner.
    It is a per-launch mode: to_dict no longer writes it and from_dict no longer
    restores it, so it comes from the command line or the checkbox and lasts one
    session. A settings.json already holding simulate=true is now ignored rather
    than obeyed, so nobody has to find and delete the file.
    [config.py]
2026-09-17 Find the lock-in's GPIB terminator instead of assuming CR
    The 5302 predates SCPI and its reply terminator depends on its rear-panel
    switches: CR, LF, CR LF, or nothing but EOI. VisaTransport hardcoded CR both
    ways with no way to change it, and the wrong guess means the instrument never
    sees a complete command, never answers, and the read fails with VI_ERROR_TMO -
    which reads as a dead instrument rather than a terminator mismatch. NI MAX
    finding the device at PAD 12 while PyFERRO timed out is what that looks like.
    probe_terminations walks the eight plausible pairs, cheapest first, and keeps
    the one where ID answers 5302. The old default is tried first, so a working rig
    is unaffected. Test lo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
    [acquisition.py, transports.py]
2026-09-17 Say why a lock-in command failed, and cover the 5302's real terminators
    Reading the manual rather than guessing at it. Section 8.5: the 5302 offers CR
    or CR LF only, never LF alone, and the input and output terminators are chosen
    independently - so all four pairings occur. The probe list had LF-only entries
    the instrument cannot produce and was missing both mixed CR/CRLF pairs, which
    are the ones most likely to catch someone out.
    Section 8.7 documents a status byte that a serial poll reads even after a
    command has been rejected: invalid command, parameter error, reference unlock,
    overload. That was being thrown away, leaving a bare VI_ERROR_TMO that says
    nothing about the cause. A failed qu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
    [transports.py]
2026-09-17 Let Stop interrupt the terminator search
    The probe I added costs a VISA timeout for each of eight terminator pairs when
    the instrument is silent - up to 16 s on the acquisition thread, while stop()
    only joins it for 10. So Stop returned with the loop still running and failures
    kept logging after the button was pressed.
    The probe now checks should_stop before each attempt and uses a 1 s timeout
    rather than the configured one, since ID is a short command; the transport goes
    back to the full timeout once a pair works. The pair that answered is remembered
    per resource, so a reconnect mid-run costs one attempt instead of eight.
    [acquisition.py, transports.py]
2026-09-17 Say when the loop cannot keep up, and settle after Device Clear
    An instrument that is not answering costs its whole timeout on every sample, so
    the loop quietly runs at the speed of the slowest one. With the interval at
    0.2 s and a lock-in that never replies, readings arrive seconds apart and the
    display just looks frozen. The loop now times each instrument and, at most
    every 30 s, says how long a reading actually takes and which instrument the
    time went to.
    Also: VisaTransport sends Device Clear on open and then queries immediately.
    That resets the instrument's communications processor and the 5302 can swallow
    the next command, which looks like a dead instrument rather than a lost byte.
    Wa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
    [acquisition.py, transports.py]
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2026-09-17 Wait for command complete before sending the next lock-in command
    Manual section 8.7: the 5302 asserts bit 0 of its status byte when it has
    finished with a command and will accept another. We were firing ID, SEN, XTC
    back to back with no wait, which loses commands a few exchanges into a run -
    it shows up as a timeout on a perfectly valid command while the first command
    after opening works fine.
    The VISA transport now serial-polls for command complete after each exchange.
    If the instrument never settles, or cannot be polled at all, it carries on
    rather than turning a slow instrument into an error.
    [acquisition.py, transports.py]
2026-09-17 Stop a late lock-in reply crashing with IndexError
    A reply left unread makes the next command's reply arrive one command late, so
    a good SEN or XTC answer comes back as the previous response. An ID reply of
    5302 read as a sensitivity index then indexes a 22-entry table and raises
    IndexError, which says nothing about what went wrong.
    Two changes. The transport drains anything still queued after each exchange,
    using status bit 7 (data available) and a short timeout so draining can never
    cost a full read timeout. And the setting indices are range-checked at the
    point they are read: SEN is 0-21 and XTC 0-18 in the manual, tables 9-16 and
    9-19, so anything else means the replies are out of step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
    [lockin5302.py, transports.py]
2026-09-17 Replace the serial-poll handshake with a plain gap between commands
    Polling the 5302 for command complete after every exchange, as manual section
    8.7 describes, made things worse rather than better: ID started failing where it
    had been answering. Two hundred bus operations after each command is not what a
    1990s instrument expects from a control program.
    A 50 ms gap achieves what the handshake was for - not sending a command while
    the instrument is still dealing with the last one - and touches nothing else.
    The drain also moves to where it belongs: only after a failure, where a reply
    may still be on its way and would otherwise be read as the next command's
    answer. The working path is left al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
    [acquisition.py, transports.py]
2026-09-17 Scan for GPIB listeners without MAX or administrator rights
    MAX will not open its GPIB property pages without an administrator, and the
    lab account does not have one. The useful part - ibic's ibln - needs no such
    rights, so call it directly through NI-488.2.
    ibln addresses each device and watches the handshake lines without sending a
    command, which is the lowest-level question available: it separates "nothing is
    accepting addressing", the no-listeners condition LabVIEW reported, from an
    instrument that is addressed fine but never answers. Those need opposite fixes.
    [gpib_check.py]
2026-09-17 Flush the instrument's output queue when opening it
    ibic on the rig read back two stacked 5302 replies: answers to commands an
    earlier program sent and never collected. Anything left there is handed to us
    as our own first reply, so every read is one command out of step from the
    start - which is how an ID reply turned up where a sensitivity index of 0..21
    was expected.
    Device Clear alone did not settle it, so drain the queue explicitly after
    opening, with the same short timeout used after a failure.
    [transports.py]
2026-09-17 Bisect the open sequence in the GPIB check
    ibic talks to the lock-in cleanly while the program cannot, and the only
    difference is what the program does when it opens the resource: Device Clear, a
    settle delay, and a drain of the output queue. I have been guessing which of
    those is at fault and changing all three.
    The check now runs the same ID query through each combination in turn and
    prints PASS or FAIL per step, so one run on the rig says which one breaks it.
    [gpib_check.py]
2026-09-17 Clear the lock-in and query it immediately
    Bisected on the rig: Device Clear followed straight away by the first command
    works, and inserting a pause between them does not. Both the pause and the
    drain that followed it were mine, added on a theory about Device Clear
    resetting the instrument's communications processor - the theory was wrong, and
    ibic had already shown the clear alone empties a stacked output queue.
    [transports.py]
2026-09-17 Retry the lock-in, and measure how marginal the link is
    The open-sequence bisect fails on different lines each run, so it was measuring
    an unreliable link rather than the open sequence, and the settle delay I removed
    on the strength of one sample was never the cause. A link that drops random
    exchanges is a connection problem, and no arrangement of commands fixes it.
    So: measure it instead of guessing. The check now repeats the ID query twenty
    times and reports the success rate with the failure kinds, which says whether
    reseating a connector or swapping a cable actually helped.
    And tolerate it. The VISA transport retries a failed exchange twice, clearing
    any reply still on its way in betwee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
    [acquisition.py, gpib_check.py, transports.py]
2026-09-21 Scale Y without Expand, and stop guessing when EX fails
    Expand multiplies the gain of the x channel only - manual section 4, "causes the
    x channel output to be multiplied by 10", and the EX entry in section 9. We
    divided Y by ten as well, so Y read ten times too small whenever expand was on.
    The simulator made the same assumption, so no test could see it. Both now
    follow the manual, and a test pins X and Y against a scripted instrument.
    A failed EX query used to switch expand detection off for the rest of the
    connection and report expand as off. It was meant for firmware that rejects
    the command, but a timeout set it too, and on a link that drops the odd
    exchange that would read X ten times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
    [acquisition.py, lockin5302.py, simulated.py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]
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2026-09-24 Pin the engine to LuaLaTeX in the files themselves
    The manual only builds under LuaLaTeX -- unicode-math and luamml rule out
    pdflatex -- but nothing in a checkout said so, and a personal ~/.latexmkrc was
    carrying the setting on one machine.
    Start every .tex file with `% !TEX program = lualatex`, which TeXShop,
    TeXstudio and TeXworks honour, and add tikz/.latexmkrc so a figure built from
    its own directory gets the engine too: latexmk reads the rc file in its working
    directory only, not the parent's.
    The README now also says which LaTeX Workshop recipe to pick. The default one
    passes `-pdf`, and a command-line engine flag beats the rc file, so it would
    run pdflatex and fail on unicode-math.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
2026-09-24 Record what the 5302 GPIB link measurements showed
    No driver change: the timeouts trace to the marginal link, not to the terminator
    or the command sequence. Measured on the rig, the raw reply to ID is a bare CR
    ending in EOI, so read CR is right and read CRLF only works through EOI. An
    abandoned query leaves its reply queued, Device Clear does not flush it, and
    draining after the clear at open made first-query success worse (3/8 vs 6/8),
    so it stays out.
    CLAUDE.md now holds those findings so they are not re-derived, and gpib_check's
    marginal-link advice no longer says to avoid a hub: the vendor's fix for a
    GPIB-USB adapter that locks up at random is an externally powered one.
    Co-Authored-B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
    [gpib_check.py]
2026-09-24 Give the lock-in time to parse a query before reading its reply
    Connecting to the lock-in, and the Test button, timed out on ID. The program read
    the reply the instant it sent the query; the 5302 had not finished parsing, so the
    reply arrived late and landed on the next query ("SEN answered 5302"), after which
    every attempt failed - it looked like a dead link.
    VisaTransport takes reply_delay_s and waits that long between the write and the
    read, passed as pyvisa's query(delay=). The lock-in uses its existing 50 ms; the
    multimeter keeps 0. Measured on the real 5302 through the program's own connect and
    Test path: 0/10 before, 15/15 after, and 60/60 acquisition samples with no retries.
    pixi r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
    [acquisition.py, gpib_check.py, transports.py]
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2026-09-28 Choose the lock-in and multimeter model on the Instruments tab
    The SR830, Keithley 199 and 5301A drivers now match the 5302 and
    34401A drivers method for method, so the acquisition loop, the Test
    buttons, simulation and the file header work with any of them.
    Fixes from the review: the Keithley reads with its prefix so an
    overflow is an error rather than a 1e10-ohm reading; the SR830 reads
    its latching status byte once per sample; the 5301A is opened with the
    5302's reply delay and no longer claims more than it knows.
    [acquisition.py, config.py, hp34401a.py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]
2026-09-28 Fix review findings: Keithley Zero, SR830 status retries, expand at start
    - Keithley 199: send Z0 in the setup string. Zero can be a saved power-up
    default that the device clear restores; its readings carry a Z prefix
    (fig. 3-6), which the parser refused, so every reading failed.
    - SR830: LIAS? clears on read, so if the query needed a retry the latched
    bits may be gone. Flag that sample as overloaded rather than miss one.
    - Log an offset/expand that is already on at the first sample, not only
    a later change, as the README and changelog describe.
    Claude-Session: https://claude.ai/code/session_01HGN5Twgn3v5USaDgoGuzP8
    [acquisition.py, keithley199.py, sr830.py]
2026-09-29 Remove the 5301A lock-in, and record the SR830 and 34401A on the bus
    The 5301A is not needed. Its driver, simulator, model choice, log and header
    warning, tests and documentation go; it was never released, so the changelog
    simply no longer mentions it. A saved setting still naming it falls back to the
    5302 on the Instruments tab, as any unknown model does.
    The new drivers were checked on the rig. The SR830 at GPIB 8 answers through the
    program's own paths: 10/10 Test-button connects, 60/60 samples with no retries,
    and a recorded run whose header carries its settings. Its input is currently over
    range at 50 mV, and every sample was flagged as overloaded, as it should be. The
    HP 34401A at GPI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
    [acquisition.py, config.py, simulated.py]
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2026-09-29 Discard the first temperatures after connecting, and refuse impossible ones
    The first readings of a run showed about -3000 C and squashed the plot. A CND3
    status word outside the five fault codes the manual lists decodes as a huge
    negative temperature (8000H is -3276.8 C). decode_temperature now refuses any
    value below -999.9 C, lower than any of the controller's inputs can read, as a
    controller fault.
    As asked, the first 3 temperatures after the controller or multimeter connects
    - at the start of a run or on a reconnect - are also discarded. They are
    written as nan with a new flag, 16, "temperature discarded just after
    connecting", rather than the error flag, since the instrument did answe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
    [acquisition.py, cnd3.py, datafile.py]
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2026-09-29 Pull the latest code before pixi run start
    start now depends on an update task, tools/update.py, which runs
    git pull --ff-only and reports in one line. It never stops the program
    starting: offline (20 s limit, no password prompt), a local edit in the way,
    missing git, or a folder that is not a clone each print a note and start the
    code as it is. It only fast-forwards, so it never makes a merge commit on the
    lab PC, and it says when the pull changed pixi.toml or pixi.lock.
    pixi run start --skip-deps starts without updating.
    Checked in a scratch clone: two commits behind fast-forwards; a local edit to a
    changed file reports the refusal and leaves the code alone; outside a clone it
    is silent.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
2026-09-29 Treat being offline as normal when updating at start
    Offline, the update step printed git's "fatal: unable to access" text. It never
    stopped the program, but it read as an error. Now it prints one line, "update:
    offline - starting without updating".
    A network that never answers also waited about 21 s, twice the limit: on Windows
    git's network helper outlives git.exe and holds the output pipe open. Output now
    goes to temporary files and a timeout kills the whole process tree, so the wait is
    10 s. Measured: unreachable 10.6 s, no DNS 0.6 s, both exit 0 and start runs.
    [update.py]
2026-09-29 Split heating and cooling by turning points, not a local slope
    The temperature wobbles by degrees (the relay cycling the heater near the probe),
    and the 60 s slope tracker flipped between heating and cooling on every swing,
    recolouring the plots and counting a new segment each time.
    DirectionTracker now averages the temperature over 120 s and changes direction
    only when the average has come back 3 C from the highest (or lowest) point
    reached. Scored on synthetic 25 -> 150 -> 25 C runs at 1-10 C/min with +-5 C
    swings of period 5-120 s: exactly one turn every time, within 4 s of the true
    peak, against up to 999 for the old tracker and 30-47% of points mislabelled
    for swings of 30 s and slower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
    [acquisition.py, analysis.py, datafile.py]
2026-09-29 Read the 5302's front-panel set-up over GPIB; add its settings to the lab manual
    The lab manual's lock-in settings were for the older 5209. It now has a 5302
    table for the capacitance measurement: each setting's value, how to set it from
    the front panel, and its GPIB command, all from the 5302 manual. A note gives
    the two values that differ from the 5209: R0 = 450 ohm (5302 manual 4.6), and
    V0 = 1.000 V, since the 5302 has no 3 V range and the in-phase signal would
    overload 1 V.
    The driver reads the same settings back (IE, OA, OF, DR, FLT, PREAMP, P, manual
    ch. 9). The Test button shows them and each data-file header records them. Each
    is read on its own and becomes "not read" if it fails,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
    [acquisition.py, lockin5302.py, simulated.py]
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2026-09-29 Check the lock-in against the lab manual in the app; note the faulty PV
    Test lock-in now compares the 5302's settings, read over GPIB, with the lab
    manual's capacitance table: a table under the result gives each setting now,
    the manual's value, and for anything that differs the key that changes it.
    Starting a recording logs any difference as a warning and writes it into the
    header (lockin_setup_check). Checked on the rig: it flags the six settings that
    were found wrong by hand today and passes reference, frequency and input.
    Test controller also shows output 2, an output-1 limit below 100 %, and the
    setpoint mode and ramp rate (1013H, 110EH, 1120H, 1104H, 1124H), each read on its
    own so a d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
    [acquisition.py, analysis.py, cnd3.py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]
2026-09-29 Set the 5302 from the app, and record all of its settings during a run
    A new Lock-in tab reads the 5302's settings and changes them: reference,
    oscillator frequency and level, sensitivity, expand, time constant, filter,
    reserve and input. "Lab-manual values" fills in the lab manual's table; Apply
    lists the commands, asks, sends only what differs, and reads the settings back
    into the tab and the lab-manual check.
    During a run the tab never touches the bus itself: Acquisition.set_lockin stores
    the request and the loop sends it between samples, annotates what was sent, and
    reads back at once, so the file shows both what was asked for and what took
    effect. Idle, the tab opens its own connection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
    [acquisition.py, lockin5302.py, simulated.py]
2026-09-30 Bring the documentation up to date with the code
    - README (root and pyferro): install is now a git clone run with pixi,
    with the offline bundle kept as an unused fallback; the SR830 and
    Keithley 199 with their addresses; pixi run gpib; the multimeters'
    front-panel settings; the CND3 registers read for Test; the 5302's
    set-up commands; shortcuts, header lines and troubleshooting rows
    for recent messages. The test count is no longer quoted.
    - drivers-and-daq.md: setting the 5302 (SETTABLE, apply, the OF/OA
    encoding), the lab-manual check, the shared driver interface as it is
    now, the CND3's status/setup, and the simulator's fakes.
    - CHANGELOG: pixi run gpib (added after 1.0.2) an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
    [cnd3.py, gpib_check.py, hp34401a.py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]
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2026-10-02 Manual: drop the 5302 appendix, trim the PyFERRO appendix
    The manual now covers only the SR830. The 5302 appendix, its table and
    photo are gone, and so is the pixi run gpib line that pointed at it (that
    command only checks a 5302). The PyFERRO appendix keeps what a student does
    at the bench and the screenshots, and points to the README for the rest.
    The app still supports the 5302; its checks now name "the 5302 capacitance
    set-up" rather than a lab-manual table that no longer exists. Rebuilt
    main.pdf and main-tagged.pdf (60 pages).
    [lockin5302.py, simulated.py]
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
